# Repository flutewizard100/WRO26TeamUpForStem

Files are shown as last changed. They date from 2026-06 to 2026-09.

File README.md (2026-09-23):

# Future Engineers WRO2026: BRB Robotics

## Team Intro

We are team BRB Robotics from Charlottesville, Virginia, USA.

Dorina, ....

Sagnick, ... a few words about yourself

### Team Pictures
TODO we need to take them today

### Robot Pictures
Here is our robot.
<p>
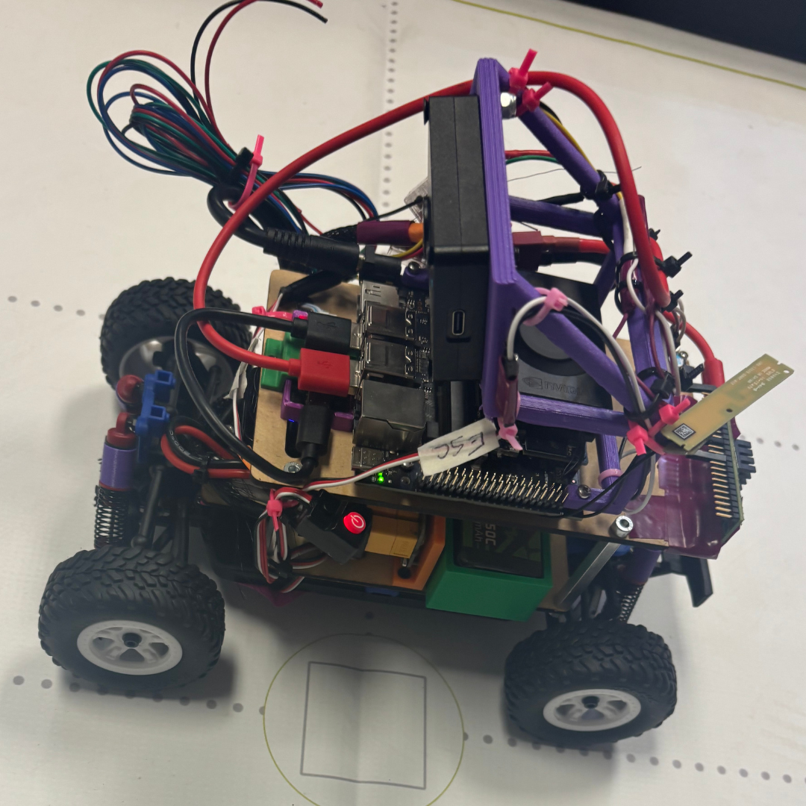
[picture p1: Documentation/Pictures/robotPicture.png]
  
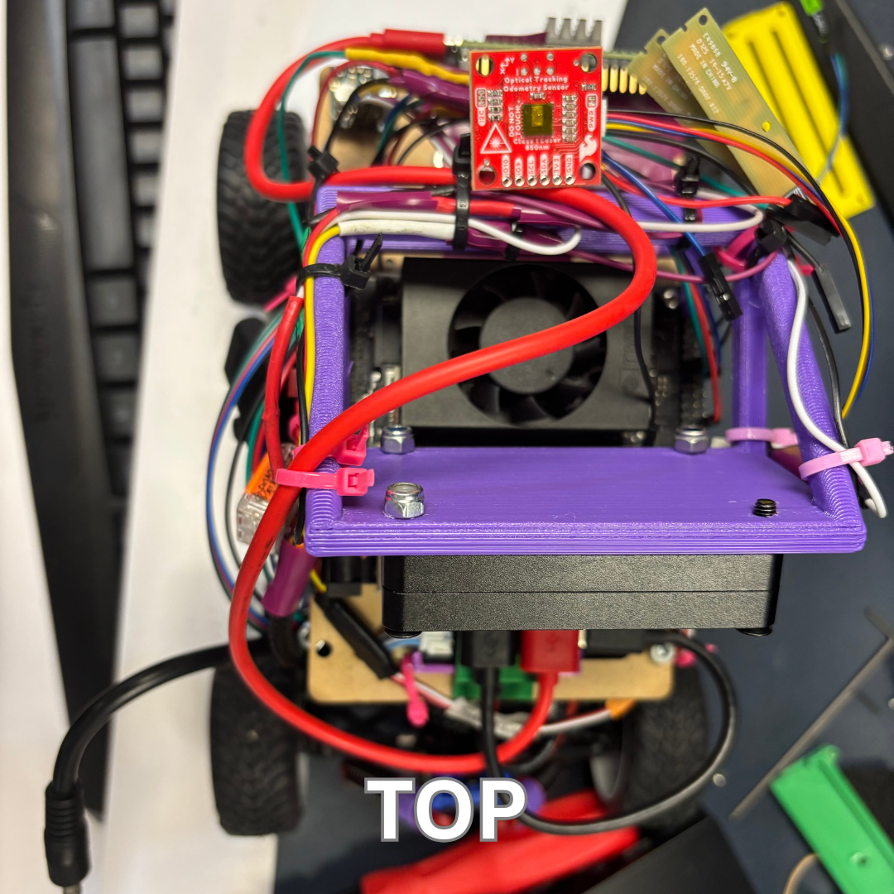
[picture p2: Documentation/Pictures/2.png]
  
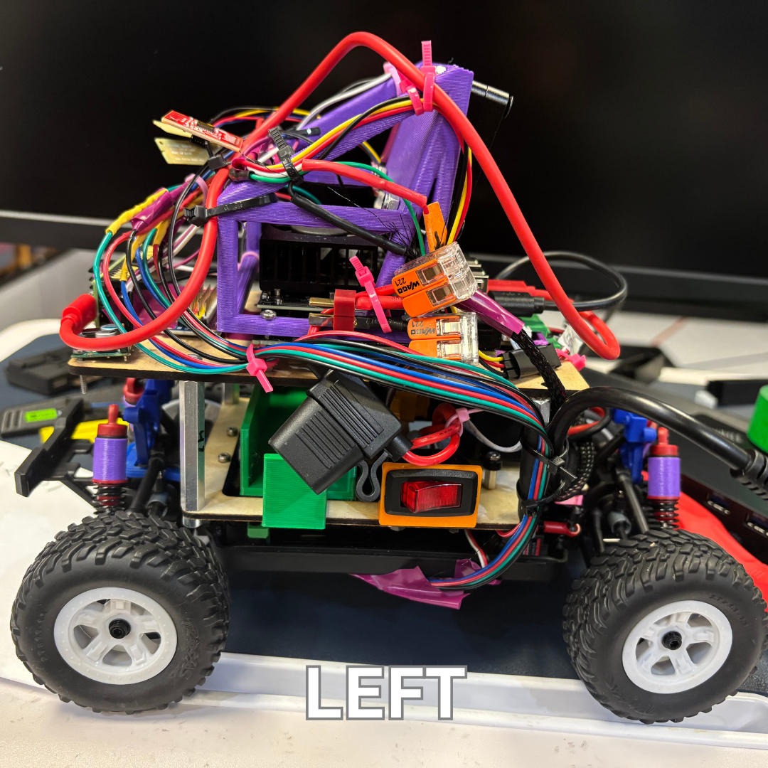
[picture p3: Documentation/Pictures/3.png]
  
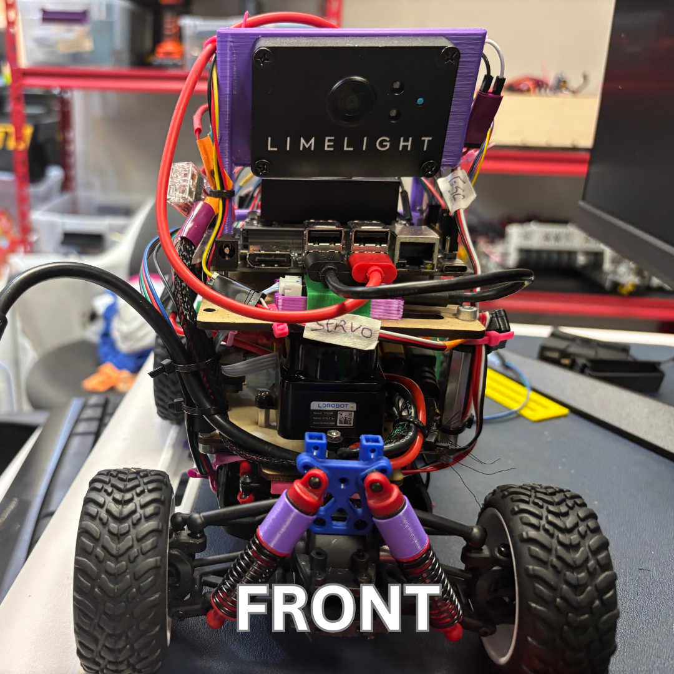
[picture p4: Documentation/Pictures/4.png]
  
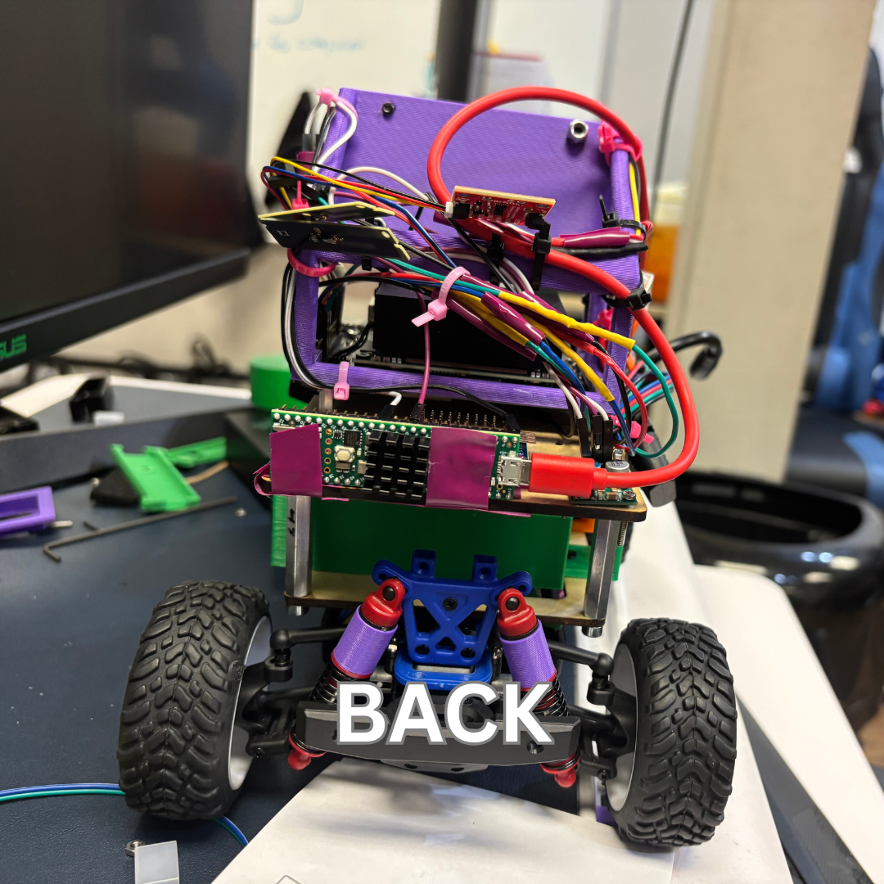
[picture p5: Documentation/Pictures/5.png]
  
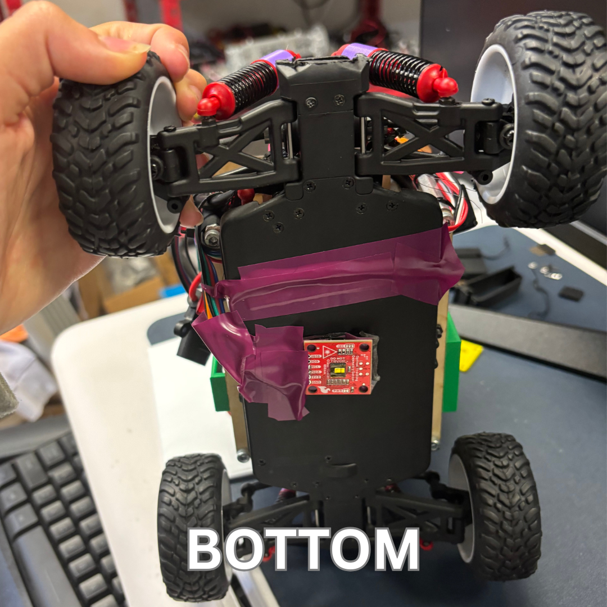
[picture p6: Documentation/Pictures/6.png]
  
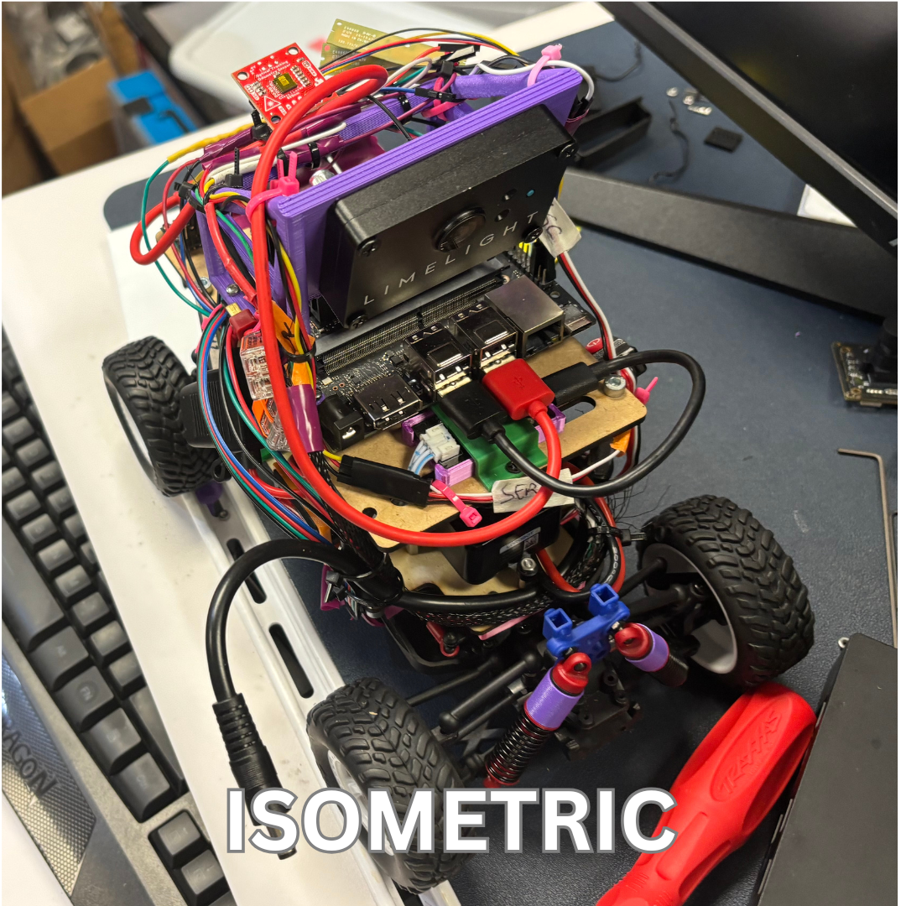
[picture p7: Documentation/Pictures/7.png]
  
</p>

## Bill of Materials

### Mobility/Drive Train

The current version of the robot uses the following components:
- Modified *LaTrax Dessert Prerunner* base available from [Amazon](https://www.amazon.com/dp/B07TV8HMC5?lv=shuf&channelId=500&plpRedirect=mhFallback), [Traxxas](https://traxxas.com/latrax-desert-prerunner-76064-5), or RC cars retailers.
- Motor: *ARRMA MEGA 380 BRUSHED MOTOR* available at [Amazon](https://www.amazon.com/dp/B0CLDRTG4G?ref=fed_asin_title)
- Servo: *Traxxas Metal Gear 2265* available from [Traxxas](https://traxxas.com/2265-high-torque-metal-gear-sub-micro-servo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)  and other retailers.
- Motor gear: *0.5M 60T Steel Spur Gear for Traxxas LaTrax 1/18 RC Cars 7640* available from [Amazon](https://www.amazon.com/dp/B0DK6524Z9?ref=fed_asin_title)  and other retailers.
- Electronic Speed Controller: *HOBBYWING QUICRUN WP 1080 G2 Brushed 2-3s* available from [Amazon](https://www.amazon.com/dp/B0DK6524Z9?ref=fed_asin_title)  and other retailers.

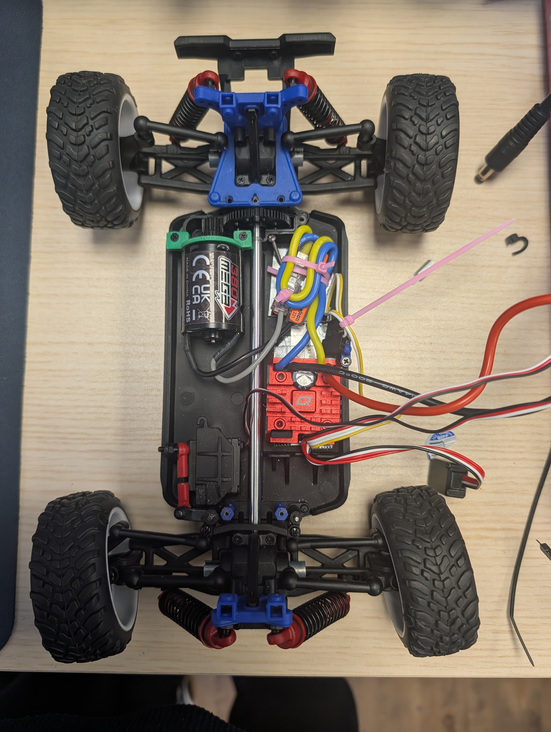
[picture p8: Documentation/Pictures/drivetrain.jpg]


### Power

1. **Battery**: *Ovonic air lipo 3s 3000 mAh 11.1v* available from [Amazon](https://www.amazon.com/dp/B0DF2BL8H1?ref=fed_asin_title) and other retailers.
2. **Power Distribution Board**: *XT60 to 4 Channel XT60 Plug Power Distribution Board* available from [Amazon](https://www.amazon.com/dp/B0FQTJSRVB?ref=fed_asin_title) and other retailers.
3. **Voltage Regulator**: *5V, 3A Step-Up/Step-Down Voltage Regulator S13V30F5* available from [Pololu](https://www.pololu.com/product/4082) and other retailers.
4. Power Switch

### Sensors

1. **IMU + Odometry**: *SparkFun Optical Tracking Odometry Sensor - PAA5160E1 (Qwiic)* available from [Spark Fun](https://www.sparkfun.com/sparkfun-optical-tracking-odometry-sensor-paa5160e1-qwiic.html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)
2. **Lidar**: *STL-27L 360° DTOF LIDAR Sensor (UART, 25m)* available from [DFROBOT](https://www.dfrobot.com/product-2726.html).
3. **Camera**: *Limelight 3A* available from [GoBilda](https://www.gobilda.com/limelight-3a-smart-camera/) and other retailers.

### Computing Components

1. **Main Computer**: *Jetson Orion Nano Developer Kit B01 8G* . The model we used was replaced by [VIDIA Jetson Orin Nano™ Super](https://www.nvidia.com/en-us/autonomous-machines/embedded-systems/jetson-orin/nano-super-developer-kit/).

2. **Low-level Controller**: *Teensy 4.1* available from [Amazon](https://www.amazon.com/dp/B08CTM3279?ref=fed_asin_title) and other retailers.

## Other Materials
- *Pololu Isolated USB-to-I²C Adapter with Isolated Power* available from [Pololu](https://www.pololu.com/product/5397) and other retailers.
- Medium Density Fiberboard/Black Acrylic/Wood for fabricating the two plates.
- PLA Fillament for 3D printing the motor connector, and mounts for various electronic components.
- Screws. We used screws we had in the robotics center including origininal screws from the Traxxas car, [M4 12 mm socket screws](https://www.gobilda.com/m4-socket-head-screws?srsltid=AfmBOooi6TK-TZ9bD9ic7EdKZm5Tyzp37X25FX4myRjO1b7F6xaQRzz2), and a variety of [M3, M2.5, and M2](https://www.mcmaster.com/products/screws/system-of-measurement~metric/thread-size~m3/thread-size~m2-5/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) screws.
- Standoffs. As with the screws, we used standoffs we had available in our lab. We used 4 [GoBilda 8mm REX™ M4 x 0.7mm Threads, 48mm Length](https://www.gobilda.com/1516-series-8mm-rex-standoff-m4-x-0-7mm-threads-48mm-length-4-pack/)  and 4 [Male-Female Threaded Hex Standoffs](https://www.mcmaster.com/products/threaded-spacers/standoffs-2~/male-female-threaded-hex-standoffs-2~~/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).
- [Dupont wires](https://www.amazon.com/dp/B01EV70C78?ref=fed_asin_title)
- Electrical Tape
- small zip ties
- [XT60 female connector to a DC barrel jack plug](https://www.amazon.com/5-5mm%C3%972-1mm-Extension-Connector-Battery-Portable/dp/B0FK2HSQSM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)
- [14×14×7mm Aluminum Heatsink with Conductive Adhesive Tape](https://www.amazon.com/dp/B0CFKHNTDV?ref=fed_asin_title&th=1)
- fuse

## Assembly and Manufacturing

We structured our car in three layers.

### Base Layer

#### Prepare the Base
Strip all the components off the the *LaTrax Dessert Prerunner* until you are left with only the components shown in the picture below. Also, remove the motor gear assembly. Save all the screws for later use.
<p>
  
</p>

#### Install the ESC

The location of the ESC is shown in the image below.
 <p>
  
</p>
We secured the ESC to the base layer with double-sided tape.

#### Attaching the motor

For attaching a stronger motor to the base, we removed the top gearbox housing and 3d printed a new one to fit the new, larger and more powerful motor.

1. Replace the platic gears in the original car with the metal ones.
2. 3D print the motor mount
3. Secure the motor in the new mount making sure the gears connect properly.

#### Attaching the servo

 For replacing the servo we simply got one with the same dimensions and replaced it with no need for any new mounts.
 
#### Attaching the SparkFun Odometry

We also conected the OTOS sensor to the bottom of the car for odometry readings. We used double-sided tape and electrical tape.
 
#### Connection with the first layer

 To be able to mount new compontents we replaced the blue plate with a new wooden laser cut mount. We connected the back directly to the traxxas base using the original screws.
 In the front, we used a 3D printed block to ensure the first layer is perfectly horizontal. We used the original screws to connect the front of the first layer.

### First Layer

This layer consists of a laser-cut, wooden base plate that holds mounts for electronic components. Mounts for the battery, the on/off switch,and the Power Distribution Board are 3D printed using PLA and screwed into the base plate. The Lidar is simply mounted by screwing it in directly to the wooden plate. It also supports four metal GoBilda standoffs that connect the top plate. We choose wood for the material because it is easy and fast to laser cut, and it is less expensive so we have lots of spare material in case the top and middle plates break.

<p>
  
  
</p>

### Second Layer

The top plate is much like the middle plate; except for the shape and the electronics it holds. It is also made of wood and is laser-cut and attaches four different components:
- The Jetson Nano is directly screwed into the board suported by standoffs.
- We connected the teensy perpendicular to the wooden plate.
- The 3D printed camera mount is screwed into other holes on the Nano board.
- The I2C to USBC adapter is connected using mounts.
 <p>
  
  
 </p>

## Power Wiring Diagram

As seen from the diagram below we have three separate braches powered directly from the battery so that a power hungry component does not starve others.

1. Power Distribution board (PBD) ==> ESC ==> Motor
2. PBD ==> Step-Down Voltage Regulator ==> servo (power+ground) and Teensy (ground)
We planned to power the teensy from the Voltage Regulator. For software development it is easier if we power the jetson from the wall and power the Teensy, lidar, and camera from the jetson.
A robust competition wiring is to connect the Teensy to the Jetson using a data only cable and power from the Voltage Regulator.
3. PBD ==> Jetson

==> Camera through the USBC to USBA cable

==> I2C adapter with a USBC to USBA cable ==> Lidar with an I2C cable

==> Teensy with MicroUSB to USBC or USBA

==> Odometry (3.3V pin + ground)

## Data Wiring

The connecting cables between Jetson Orin and lidar, camera, and Teensy are also data cables.

The servo control wire is connected to the Teensy, as well as the ESC control wire.

The odometry control wires (SDL and SCL) are connected directly to the first I2C bus on the Jetson.



## Operating System and Libraries

1. Follow [these instructions](https://ubuntu.com/download/nvidia-jetson#jetson-orin-nano) to install Ubuntu 24.04 on the Jetson Orin.
2. Follow [these instructions](https://docs.ros.org/en/jazzy/Installation.html) to install the ROS2 Jazzy library.
3. Follow [these instructions](https://github.com/micro-ros/micro_ros_setup) to install the [micro-ROS] on the Teensy.

## The stucture of the software

The ROS2 system relies on a process called `ros_core` which facilitates the communication between different parts the the robot.
Each sensor and actuator has its own process, called a node. The nodes representing physical component nodes are connected to other nodes to implement the entire robot behavior.

The nodes communicate through a publisher-subscriber mechanism. Nodes can subscribe to receive messages of a certain type on a topic, whithout know which nodes publishes on that topic. Nodes can also publish on several topics.

To start the entire system of nodes, ROS uses a system of launch files.

Before starting any work session on a terminal, the user must run the following command:
```
source /opt/ros2/jazzy/setup.bash
```

The user must change directory to the `WRO26TeamUpForStem` repository.

To command to compile the code is
```
colcon build
```

Once the build is complete, then the user must run the following command:
```
source install/setup.bash
```

We created a system of launch files to start different parts of the system.

To launch the hardware components we use the command
```
ros launch WRORobot harwdare.launch
```
A graph of the nodes and topics is available [here](hardwarenodegraph.png)

To launch the full simulation stack (sim + Nav2 + SLAM + mission), use:
```
source /opt/ros/jazzy/setup.bash && source install/setup.bash
ros2 launch wro_behavior wro_mission_sim.launch.py
```

On real hardware:
```
ros2 launch wro_behavior wro_mission_hw.launch.py
```

Open and Obstacle challenges share a single unified mission node
(`wro_mission`) that auto-detects which challenge it's running based
on whether any red/green pillars are seen during the run.

When the control code is run in a simulated environment the hardware's behavior is simulated, but the navigation and behavior nodes are the ones used on the real environment.

To launch the full software stack use:
```
source /opt/ros/jazzy/setup.bash && source install/setup.bash
ros2 launch WRORobot
```

# Contents

- our repository is a ROS2 workspace with directories for major software components
1. `ldlidar_ros2` is the software provided by the vendor for the specific lidar we use.
2. `lsm9ds1_handler` and `lsmds1_imu_driver` is software for a 9-axis IMU we planned to use as a backup for the 6-axis IMU that comes with the SparkFun sensor.
3. `slam_toolbox` is a software package that subscribes to the `/odom` and `/scan` and runs a SLAM algorithm and publishes on the topic `map`
4. `WRORobot` contains the nodes representing the harware components.
5. `wro_sim` contains the nodes to creat the simulation and environment
5. `wro_nav2` 
6. `wro_behavior` programs used to code the simulation
- `t-photos` contains two photos of the team: an official team photo and a funny photo with all team members.
- `v-photos` contains six photos of the vehicle from every side, as well as from the top and bottom.
- `video` contains the `video.md` file with a link to a video that includes a driving demonstration.
- `schemes` contains one or more schematic diagrams in JPEG, PNG, or PDF format of the electromechanical components. These diagrams illustrate all of the electronic components and motors used in the vehicle and how they are connected to each other.
- `models` contains the files for models used by 3D printers, laser-cutting machines, and CNC machines to produce the vehicle's components. If there is nothing to add to this folder, the directory can be removed.
- `other` contains additional files that can be used to understand how to prepare the vehicle for the competition. This may include documentation on how to connect to an SBC/SBM and upload files, datasets, hardware specifications, communication protocol descriptions, and other relevant information.

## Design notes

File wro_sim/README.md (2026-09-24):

# wro_sim

Gazebo Harmonic simulation of the WRO Ackermann robot. Bridges the sim to
the same ROS 2 topic/frame contract that the real robot uses, so anything
built against `wro_nav2` and `wro_behavior` runs unchanged on both.

**Do NOT confuse this with Gazebo Classic or Ignition Fortress.** This
package uses `gz-sim-*` plugins and the Jazzy `ros_gz_*` bridges.

## Contents

```
wro_sim/
  worlds/
    wro_field.sdf            # copy of ../wro_map_nav2_sim.sdf
    wro_field.sdf.xacro
  models/wro_bot/
    model.config             # (URDF lives in WRORobot/urdf/, shared with real robot)
  config/
    ros_gz_bridge.yaml       # gz <-> ROS 2 topic map
  hook/
    wro_sim.dsv.in           # prepends GZ_SIM_RESOURCE_PATH
  launch/
    sim.launch.py            # Gazebo + rsp + spawn + bridges (+ optional rviz)
    sim_stack.launch.py      # top-level: sim + Nav2 + behavior
    spawn_robot.launch.py    # standalone spawn
    bridge.launch.py         # standalone bridge
    rviz.launch.py           # standalone rviz
  rviz/sim.rviz
```

## Build

```bash
# From the flat workspace root (this repo).
# rosdep can't resolve workspace-local packages; pass --skip-keys so it
# doesn't error on wro_behavior/wro_nav2/WRORobot. Colcon still respects
# these deps for build ordering.
rosdep install --from-paths . --ignore-src -r -y \
  --skip-keys "WRORobot wro_nav2 wro_behavior"

colcon build --packages-select WRORobot wro_nav2 wro_behavior wro_sim
source install/setup.bash
```

## Run

Sim stack (Gazebo + Nav2 + behavior):

```bash
ros2 launch wro_sim sim_stack.launch.py rviz:=true
# Drop a 2D Nav Goal in RViz, or:
ros2 launch wro_sim sim_stack.launch.py rviz:=true run_goto:=true goal_x:=1.0
```

Just the sim (drive with teleop):

```bash
ros2 launch wro_sim sim.launch.py rviz:=true
ros2 run teleop_twist_keyboard teleop_twist_keyboard
```

Sim + SLAM (build a map online):

```bash
ros2 launch wro_sim sim_stack.launch.py slam:=true rviz:=true

# slam_toolbox is a LIFECYCLE node and slam.launch.py does NOT wire in a
# lifecycle_manager yet. Activate it by hand from another terminal:
ros2 lifecycle set /slam_toolbox configure
ros2 lifecycle set /slam_toolbox activate

# Drive with teleop until the RViz Map display looks acceptable.
ros2 run teleop_twist_keyboard teleop_twist_keyboard

# Save. The transient_local param is REQUIRED — slam_toolbox publishes
# /map with TRANSIENT_LOCAL durability and map_saver_cli defaults to
# VOLATILE, which silently misses every message and prints
# "Failed to spin map subscription" after 2 s.
ros2 run nav2_map_server map_saver_cli -f wro_field \
    --ros-args -p map_subscribe_transient_local:=true
mv wro_field.pgm wro_field.yaml $(ros2 pkg prefix wro_nav2)/share/wro_nav2/maps/
```

The saved map's origin is anchored at the robot's pose when slam_toolbox
was activated, NOT Gazebo's world origin. When you later reload the map
with Nav2 (`slam:=false`), use RViz's 2D Pose Estimate to set the
initial pose to `(0, 0)` yaw `0` in the map frame — that places the
robot at Gazebo world `(0, 1.20)` yaw `3.14159`.

## Topic bridge

Every ROS topic below matches the real hardware's topic name — see
`INTERFACE.md` at repo root for the full contract.

| ROS topic | direction | Gazebo topic | type |
|---|---|---|---|
| `/clock` | gz -> ros | `/clock` | rosgraph_msgs/Clock |
| `/scan` | gz -> ros | `/lidar` | sensor_msgs/LaserScan |
| `/imu/data_raw` | gz -> ros | `/imu` | sensor_msgs/Imu |
| `/odom` | gz -> ros | `/model/wro_bot/odometry` | nav_msgs/Odometry |
| `/tf` | gz -> ros | `/model/wro_bot/tf` | tf2_msgs/TFMessage |
| `/joint_states` | gz -> ros | `/model/wro_bot/joint_state` | sensor_msgs/JointState |
| `/camera_info` | gz -> ros | `/camera_info` | sensor_msgs/CameraInfo |
| `/camera` | gz -> ros | `/camera` | sensor_msgs/Image (via image_bridge) |
| `/cmd_vel` | ros -> gz | `/model/wro_bot/cmd_vel` | geometry_msgs/Twist |

## TODO(measure): placeholders

The URDF (`WRORobot/urdf/wro_bot.urdf.xacro`) is the single source of truth
for physical dimensions on both sim and real robot. Every property in
that file is a placeholder; replace against the physical car or CAD:

- `wheelbase = 0.16`
- `track_width = 0.14`
- `wheel_radius = 0.033`
- `wheel_thickness = 0.025`
- `max_steer_angle = 0.5236` (30 deg)
- Chassis and sensor-mount offsets
- Link masses / inertias

When you update any of these, also update `wro_nav2/params/nav2_params*.yaml`:
- `minimum_turning_radius` on both `SmacPlannerHybrid` and MPPI's
  `AckermannConstraints.min_turning_r`
- Footprint polygon in both costmaps

Sim spawn pose defaults live in `launch/sim.launch.py` (`x=0`, `y=1.20`,
`z=0.103`, `yaw=3.14159` — centered in the narrow (0.60 m) north
corridor, facing west). Adjust to your WRO field start box.

**Do not lower the default `z`.** `z = wheel_radius + chassis_height/2`
(0.033 + 0.070 = 0.103) is the resting height with wheels on the ground.
Spawning below that (e.g. the old `z=0.073`) buries the wheels ~3 cm
underground; physics still runs and joint commands still spin the wheels,
but the chassis stays jammed and never translates. Symptom: `/odom`
integrates a fake forward velocity while `gz model -m wro_bot -p` shows
the pose unchanged.

## Real-hardware decisions already made

- **`odom -> base_link` on hardware is published by `otos_node` only.**
  EKF and Madgwick were removed from `WRORobot/launch/hardware.launch.py`
  on 2026-08-30. See that file's header comment for how to re-enable.
- **Sim `/camera`** is a plain 640x480 image, NOT a Limelight replacement.
  Real hardware uses a Limelight over NetworkTables; sim camera is for
  future ROS-side vision development.

## Gotchas encountered during first bring-up

Kept here so the next engineer doesn't re-diagnose the same problems:

- **Launch it from a plain terminal, not the VSCode Snap terminal.**
  VSCode-as-Snap leaks Snap env into subprocesses, and `gz sim` picks up
  `/snap/core20/current/lib/x86_64-linux-gnu/libpthread.so.0` — an
  ABI-incompatible libpthread — and dies with
  `undefined symbol: __libc_pthread_init, version GLIBC_PRIVATE`. The
  GUI crashes first, then the server gets SIGKILL'd. Use GNOME Terminal
  / kitty / anything non-Snap.
- **Ackermann plugin driven joints must be the rear wheels.**
  `<left_joint>` / `<right_joint>` in
  `gz-sim-ackermann-steering-system` are the joints velocity is
  applied to. Setting them to the front wheels (which are also the
  steering knuckles) results in front wheels spinning kinematically
  with no traction and the car sits still. Fixed in
  `WRORobot/urdf/wro_bot.urdf.xacro`.
- **slam_toolbox does not auto-activate.** See the SLAM run block
  above. Long-term fix: add a `nav2_lifecycle_manager` in
  `wro_nav2/launch/slam.launch.py` with `autostart: true` and
  `node_names: ['slam_toolbox']`.
- **`map_saver_cli` needs `-p map_subscribe_transient_local:=true`.**
  Without it, saves fail with "Failed to spin map subscription".

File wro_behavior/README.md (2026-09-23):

# wro_behavior

High-level behavior for the WRO robot. Mission logic, state machines, and
perception helpers live here.

## Contract

This package consumes the interface pinned in `../INTERFACE.md`. It never
imports from `WRORobot`, `wro_sim`, or any hardware/driver package. If you
find yourself wanting to depend on one, the abstraction is wrong and the
answer is a new topic/action/service in the interface, not a direct import.

## Nodes

- `wro_mission` — unified Open + Obstacle Challenge mission node. State
  machine, direction detection, waypoint dispatch, first-corner guard,
  end-of-race handling.
- `camera_map_augmenter` — subscribes to `/limelight/detections`, projects
  confirmed pillar landmarks into the map frame, publishes them as
  `PointCloud2` on `/camera_obstacles` for Nav2's obstacle layer.
- `sim_limelight_bridge` — sim-only substitute for the real Limelight
  bridge. HSV-detects pillars and lines from `/camera` and publishes
  `vision_msgs/Detection2DArray` on `/limelight/detections`.

## Perception helpers (imported by the nodes above)

- `lidar_perception.LidarPerception` — `/scan` subscription, arc queries,
  forward-edge waypoint generation.
- `camera_perception.CameraPerception` — `/camera_info` + `/limelight/detections`
  subscriptions, pillar/line semantics, pixel → map projection, landmark
  accumulator.

## Run

Sim, full stack (Gazebo + Nav2 + SLAM + mission):
```bash
ros2 launch wro_behavior wro_mission_sim.launch.py
```

Real hardware:
```bash
ros2 launch wro_behavior wro_mission_hw.launch.py
```

Trigger the start button from a terminal (equivalent to pressing the
force sensor):
```bash
ros2 topic pub --once /start_button std_msgs/msg/Bool "{data: true}"
```

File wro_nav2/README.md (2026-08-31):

# wro_nav2

Nav2 configuration, behavior tree, maps, RViz, and launch files for the WRO
Ackermann robot. Config-only — no C++ / Python nodes, no vendored Nav2.

## What's in here

```
wro_nav2/
  params/
    nav2_params.yaml       # real-hardware params (use_sim_time: false)
    nav2_params_sim.yaml   # sim-time params (use_sim_time: true, tighter inflation)
  bt/
    wro_navigate_to_pose.xml   # Nav2's default BT with Spin removed
  maps/
    wro_field.yaml         # placeholder blank 4x4 m map
    wro_field.pgm
    README.md              # how to regenerate / SLAM a real one
  rviz/
    nav2.rviz              # map + costmaps + scan + paths + AMCL pose
  launch/
    nav2.launch.py         # full Nav2 stack (wraps nav2_bringup)
    localization.launch.py # AMCL + map_server + lifecycle_manager subset
    slam.launch.py         # slam_toolbox + Nav2 planning (no AMCL/map_server)
```

## Build

```bash
# from your ROS 2 Jazzy workspace (this repo is a flat workspace — no src/)
colcon build --packages-select wro_nav2
source install/setup.bash
```

## Run

Real robot, pre-built map + AMCL:

```bash
ros2 launch wro_nav2 nav2.launch.py
```

With SLAM instead of AMCL (building a map online):

```bash
ros2 launch wro_nav2 slam.launch.py
# slam_toolbox does not auto-activate — transition it by hand:
ros2 lifecycle set /slam_toolbox configure
ros2 lifecycle set /slam_toolbox activate
```

`slam.launch.py` does not yet include a `nav2_lifecycle_manager` for
slam_toolbox. TODO: add one with `autostart: true` and
`node_names: ['slam_toolbox']` so activation is automatic.

Save the resulting map (transient_local flag is required — see
`wro_sim/README.md` for the full explanation):

```bash
ros2 run nav2_map_server map_saver_cli -f wro_field \
    --ros-args -p map_subscribe_transient_local:=true
mv wro_field.pgm wro_field.yaml \
   $(ros2 pkg prefix wro_nav2)/share/wro_nav2/maps/
```

Localization-only (no planner/controller):

```bash
ros2 launch wro_nav2 localization.launch.py
```

RViz:

```bash
rviz2 -d $(ros2 pkg prefix wro_nav2)/share/wro_nav2/rviz/nav2.rviz
```

## Design notes

- **Planner:** `nav2_smac_planner::SmacPlannerHybrid` with `motion_model: DUBIN`
  and `minimum_turning_radius: 0.30` (approx `wheelbase / tan(max_steer)` =
  `0.16 / tan(30 deg)` = 0.277). Bumped to 0.30 for margin.
- **Controller:** `nav2_mppi_controller::MPPIController` with
  `motion_model: Ackermann` and matching `AckermannConstraints.min_turning_r`.
- **Behaviors:** `wait`, `backup` (dist 0.15 m), `assisted_teleop`. `Spin` is
  **not** included — the Ackermann robot cannot spin in place.
- **AMCL:** `DifferentialMotionModel`. Acceptable for a small Ackermann on a
  smooth WRO field per plan section 2.2; revisit if pose drift is visible.
- **Footprint:** rectangle from chassis dims (0.28 x 0.16 m), not a radius.

## TODO(measure): placeholders to replace

These need real values from the physical robot / `WRO Chassis` CAD:

- `wheelbase = 0.16 m` -> `params/nav2_params*.yaml` (used indirectly via
  `minimum_turning_radius`) and `wro_sim/models/wro_bot/wro_bot.urdf.xacro`.
- `max_steer_angle = 0.5236 rad` -> same URDF, same `minimum_turning_radius`
  calculation.
- Chassis footprint corners `[[0.14, 0.08], ...]` -> both param files,
  local and global costmap.
- Max linear velocity `vx_max: 0.5`, min `vx_min: -0.35` in MPPI + velocity
  smoother -> tune to your motor limits.
- Max angular velocity `wz_max: 1.9`, rotational accel `3.2` in
  behavior_server + velocity_smoother.
- Map (`maps/wro_field.pgm` is a 4x4 m blank). See `maps/README.md`.

## Decisions the user still needs to confirm

- **TF owner on hardware.** This task assumes `ekf_node` publishes
  `odom -> base_link` (i.e. `WRORobot/config/ekf.yaml` keeps
  `publish_tf: true`). `WRORobot/WRORobot/otos_node.py` currently also
  publishes that transform — that's a **duplicate tf publisher** and will
  cause TF_REPEATED_DATA on the real robot. Choose one owner. See
  `wro_sim/README.md` "Known bugs from the plan not fixed here".
- **Camera in sim.** The sim exposes a plain 640x480 image on `/camera` (see
  `wro_sim`). Real hardware uses a Limelight over network tables — the sim
  camera is **not** a Limelight equivalent, only a placeholder for future
  ROS-side vision experiments.

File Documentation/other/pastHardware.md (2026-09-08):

# Contents:
### TODO

## Past Limelight Mount
 
 For our first attempt to mount the lidar we removed the front bumper from the LaTrax Desert Prerunner in order to attach the Limelight camera mount, which was 3d printed like many of the mounts in this autonomous vehicle.

333scrnsht

222scrnsht

these pictures show the limelight mount 3d print.

## First Prototype

#### The first prototype has a 3d printed base:

444scrnshtscrnsht555 1

#### but in the base you see here, there are only mounts for the Jetson Nano and the Arduino Teensy, but no mount for the motor or battery. So, to fix those issues, we 3d printed another base and moved the board mounts to the top plate:

666scrnsht

777 7 screenshots for documentation

here is the new prototype for the base:

888 8 screenshot for documentation

#### There are several reasons, though, to why we did not use this base prototype in the competition. First, the servo for the autonomous vehicle was too weak, and under the circumstances we did not have enough time to create an adapter to a stronger servo. Second, already listed, is the fact that we did not have enough time to perfect the existing prototype or create a new one from scratch, but we were creating a different, remote-controlled-car-based autonomous vehicle, that was used instead.

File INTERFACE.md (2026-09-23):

# WRO26 Robot Interface Contract

This document pins the interface between the three layers of the stack:

- **Hardware** (`WRORobot/`, drivers) OR **Sim** (`wro_sim/`) — one of the two
  publishes the sensor topics and consumes `/cmd_vel`.
- **Navigation** (`wro_nav2/`) — plans, controls, localizes.
- **Behavior** (`wro_behavior/`) — mission logic. Never touches hardware or
  sim internals.

Both sides of every arrow below MUST hold in both sim and on real hardware.
Any change to this file requires review from an engineer on each side.

---

## Frames

```
map → odom → base_link → { base_laser, imu_link, camera_link, *_wheel_* }
                                                       ↓
                                              camera_optical_frame
```

- `map` — global fixed frame. Published by AMCL (`wro_nav2/nav2.launch.py`)
  or by `slam_toolbox` (`wro_nav2/slam.launch.py`). Never published by
  anything else.
- `odom` — smooth-drift odom parent. Publisher differs by side:
  - **Sim**: `gz-sim-ackermann-steering-system` plugin, bridged as
    `/model/wro_bot/tf` → `/tf`.
  - **Real robot**: `ekf_filter_node` (robot_localization) fuses three
    sources into a single filtered pose and owns the `odom → base_link`
    TF edge. Sources: `/odom` from `otos_node` (primary, OTOS),
    `/odometry/laser` from `laser_scan_matcher` (LiDAR scan-to-scan),
    `/imu/data` from `imu_filter_madgwick` (yaw + yaw rate, no mag).
    If OTOS goes silent for >300 ms, EKF drops it and integrates from
    remaining sources — see WRORobot/config/ekf.yaml for weights.
    `otos_node` publishes `/odom` but not the TF (its `publish_tf` param
    is False). To run OTOS standalone (no fusion) remove the ekf/
    madgwick/scan_matcher nodes from hardware.launch.py and set
    otos_node's `publish_tf` param to True.
- `base_link` — robot body root. Owned by `robot_state_publisher`
  processing `WRORobot/urdf/wro_bot.urdf.xacro`.
- `base_laser`, `imu_link`, `camera_link`, `camera_optical_frame`, wheel
  frames — all published by `robot_state_publisher` from the same URDF.

Only one publisher per TF edge. Any duplication is a bug.

---

## Topics behavior consumes

| Topic | Type | Publisher | Rate |
|---|---|---|---|
| `/scan` | `sensor_msgs/LaserScan` | Sim: bridge from `/lidar`. Real: `ldlidar_ros2`. | ~10 Hz |
| `/odom` | `nav_msgs/Odometry` | Sim: bridge. Real: `otos_node` (raw OTOS pose). | ≥30 Hz |
| `/odometry/filtered` | `nav_msgs/Odometry` | Real: `ekf_filter_node` (OTOS + IMU + scan-matcher fused). | 30 Hz |
| `/odometry/laser` | `nav_msgs/Odometry` | Real: `laser_scan_matcher`. Fallback pose source; EKF consumes. | ≥10 Hz |
| `/imu/data` | `sensor_msgs/Imu` | Real: `imu_filter_madgwick` (Madgwick-filtered orientation). EKF consumes. | ~100 Hz |
| `/tf`, `/tf_static` | `tf2_msgs/TFMessage` | as above per edge | — |
| `/amcl_pose` | `geometry_msgs/PoseWithCovarianceStamped` | Nav2 AMCL | ~2 Hz |
| `/camera/image_raw`, `/camera_info` | `sensor_msgs/Image`, `sensor_msgs/CameraInfo` | Sim: bridge. Real: not published — the Limelight does not stream raw frames; use `/limelight/detections` instead. | ~30 Hz (sim only) |
| `/limelight/detections` | `vision_msgs/Detection2DArray` | Real: `limelight_bridge` (SSD MobileNet on Limelight 3). Sim: not published. `frame_id` is `camera_optical_frame`; each detection carries a bbox in pixels + a 3D pose in the camera-optical frame estimated from bbox height. `results[0].hypothesis.class_id` is the LL label string (e.g. `red_pillar`, `green_pillar`). Empty array published as heartbeat when nothing detected. | 30 Hz |
| `/joint_states` | `sensor_msgs/JointState` | Sim: bridge. Real: TBD. | ~30 Hz |
| `/imu/data_raw` | `sensor_msgs/Imu` | Sim: bridge. Real: `lsm9ds1_imu_driver`. Not currently fused; available for logging. | ~100 Hz |

---

## Topics behavior publishes

| Topic | Type | Consumer |
|---|---|---|
| `/goal_pose` | `geometry_msgs/PoseStamped` | Nav2 (RViz-style single-goal path; testing only) |

---

## Actions behavior calls

| Action | Type | Server |
|---|---|---|
| `/navigate_to_pose` | `nav2_msgs/NavigateToPose` | `bt_navigator` in Nav2 |
| `/follow_waypoints` | `nav2_msgs/FollowWaypoints` | `waypoint_follower` in Nav2 |

---

## Topics behavior/nav publishes → hardware or sim consumes

| Topic | Type | Consumer | Notes |
|---|---|---|---|
| `/cmd_vel` | `geometry_msgs/Twist` | Sim: bridge → AckermannSteering. Real: `Motor` node (ESC) + `Servo` node (steering servo). | Nav2 publishes via `velocity_smoother`; behavior can also publish for teleop-style tests. |

---

## Ackermann kinematics assumptions

`/cmd_vel.linear.x` is the desired forward velocity in m/s.
`/cmd_vel.angular.z` is the desired yaw rate in rad/s.

The controller and drive plugin/driver must convert `(vx, ωz)` to
`(wheel_speed, steering_angle)` using the wheelbase and steering limits
declared in `WRORobot/urdf/wro_bot.urdf.xacro`. If those values change,
both sides must re-read the URDF at launch.

There is no support for `/cmd_vel.linear.y` — the robot cannot strafe.
Nav2 params set `vy_max: 0.0` and `motion_model: Ackermann`.

---

## Guarantees each side must uphold

**Hardware side (`WRORobot/hardware.launch.py`):**
- `/odom` at ≥ 30 Hz; drift < 5 cm over a 30 s straight-line run.
- `/scan` at ≥ 10 Hz; frame_id `base_laser`.
- `/imu/data_raw` at ≥ 100 Hz; frame_id `imu_link`.
- `/cmd_vel` → motion within 50 ms.
- No writes to `/tf` except `odom → base_link` (from `ekf_filter_node`) and
  robot_state_publisher's `base_link → *`.

**Sim side (`wro_sim/sim.launch.py`):**
- Same rates and frame_ids as above, matched by `ros_gz_bridge`.
- Physics stable at 1× real time on a target dev laptop.

**Nav side (`wro_nav2/nav2.launch.py`):**
- Consumes only the topics/frames listed above.
- Publishes `/cmd_vel` (via smoother) and `map → odom`.

**Behavior side (`wro_behavior/launch/wro_mission_{sim,hw}.launch.py`):**
- Consumes only the topics/actions listed above.
- Never imports from hardware or sim packages.

---

## When something on this list changes

1. Open a PR that edits **only** `INTERFACE.md` first.
2. Get review from one engineer per side.
3. Only after that PR merges, implement the change in the affected packages.

This keeps the two engineers unblocked — if one changes the interface
unilaterally, the other's code will silently break at competition, not at
merge time.

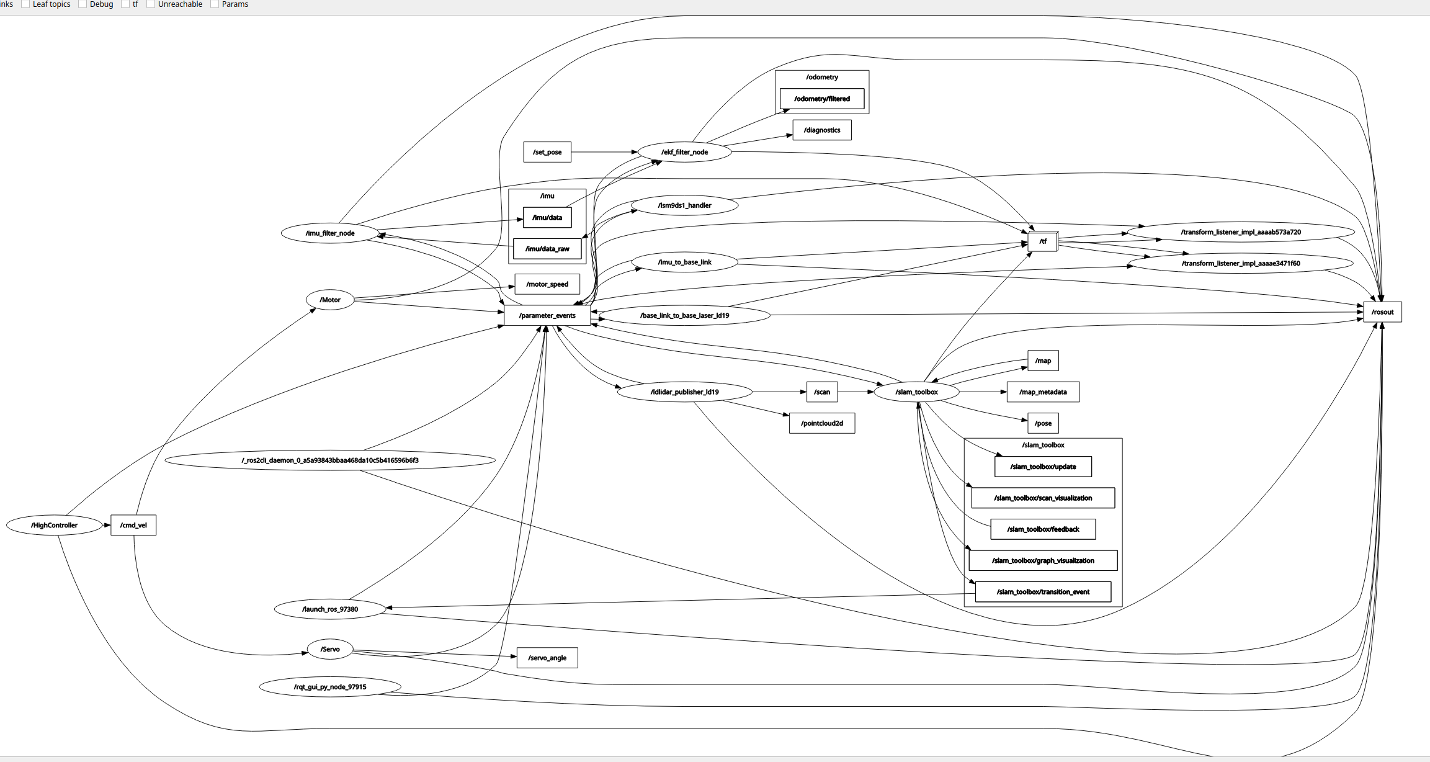
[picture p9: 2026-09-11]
hardwarenodegraph.png

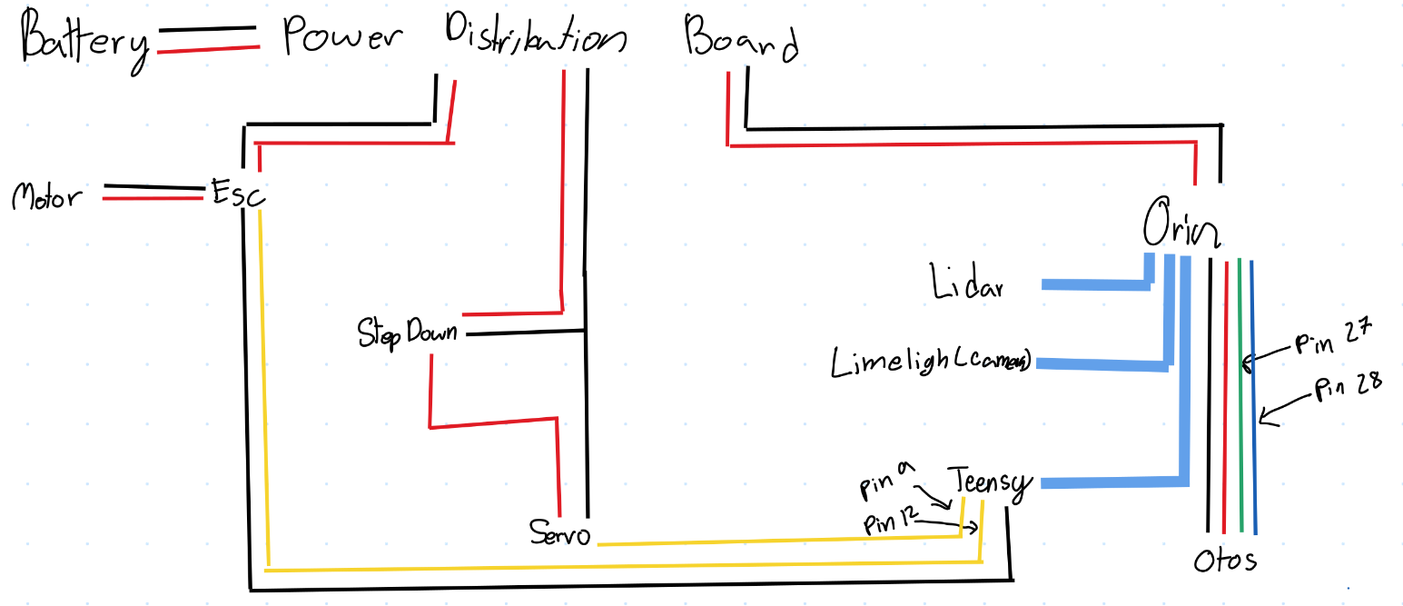
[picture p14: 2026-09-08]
Documentation/schemes/Screenshot From 2026-09-08 13-28-38.png

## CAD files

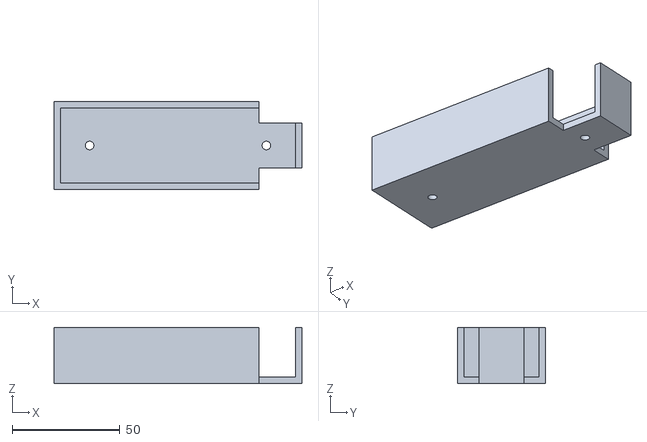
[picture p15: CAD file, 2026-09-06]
Documentation/models/BATTERY HOLDER.stl
115.0 x 41.0 x 26.0

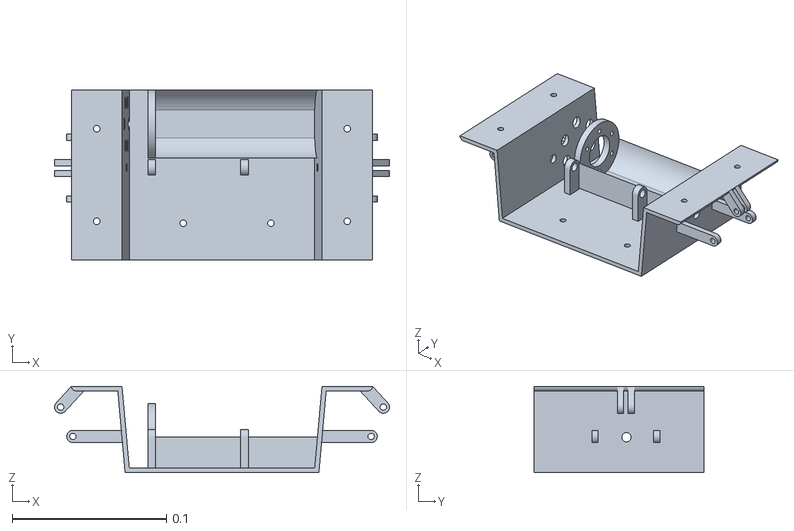
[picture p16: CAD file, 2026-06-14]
WROOldChassis.stl
0.217 x 0.11 x 0.056

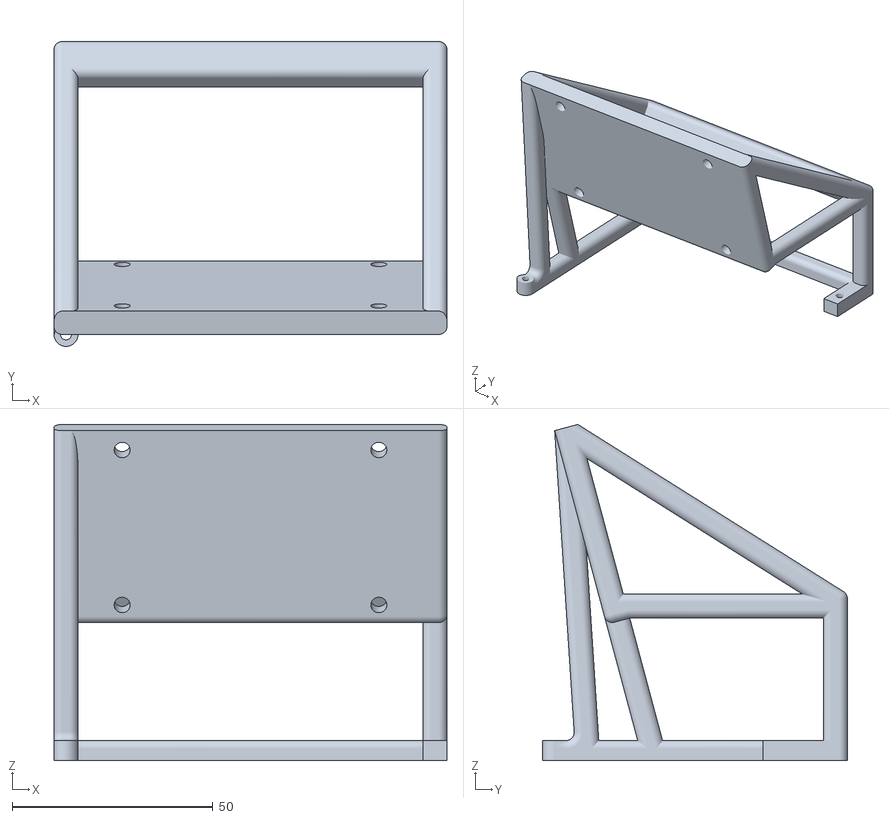
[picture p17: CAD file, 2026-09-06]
Documentation/models/LiDAR holder.stl
98.0 x 76.0 x 83.8

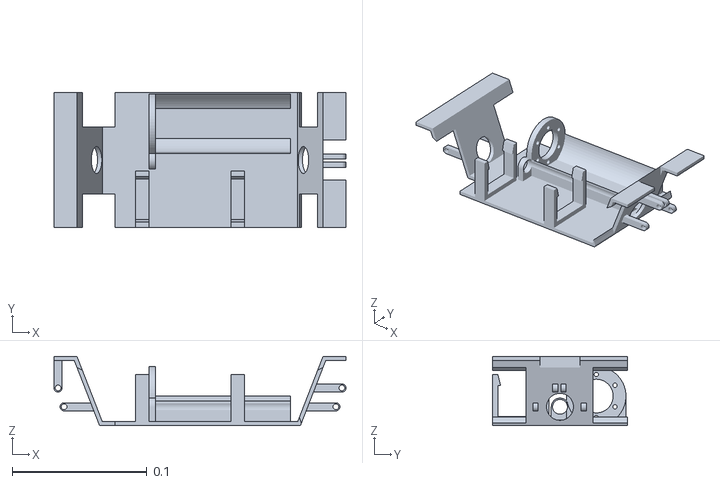
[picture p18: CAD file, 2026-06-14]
WROChassis.stl
0.217 x 0.1 x 0.0515

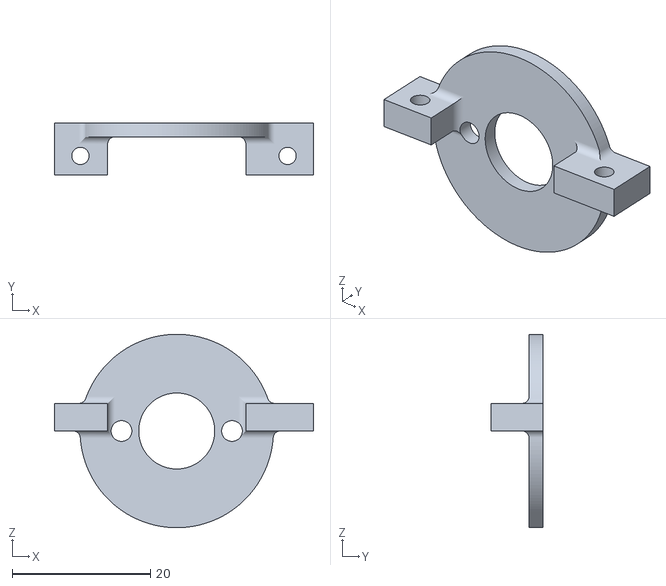
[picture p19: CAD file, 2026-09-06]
Documentation/models/MOTOR MOUNT - Part 1 (2).stl
37.5 x 7.50 x 28.0

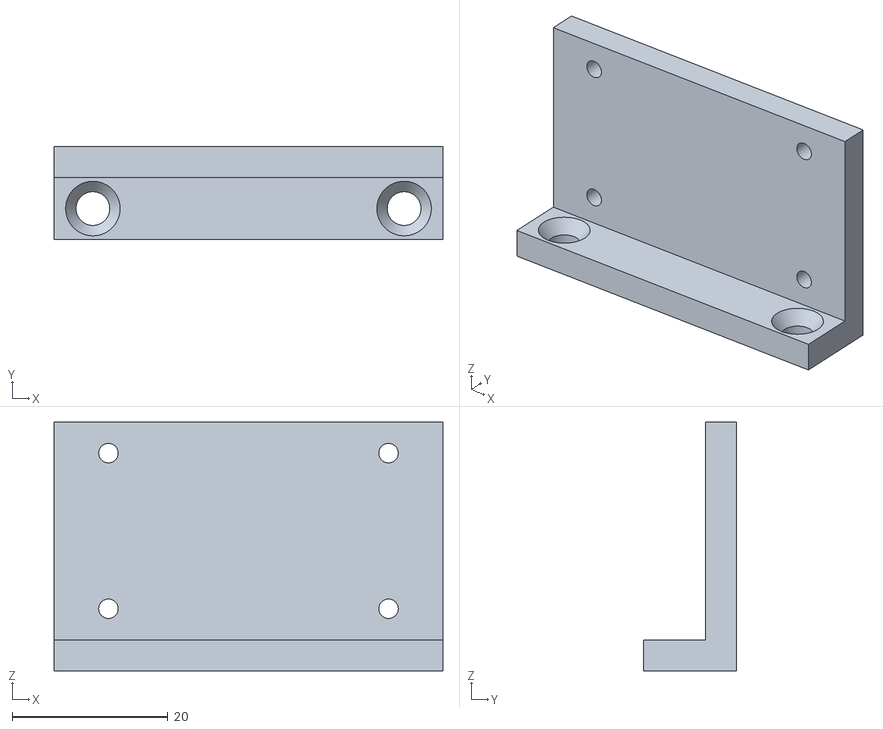
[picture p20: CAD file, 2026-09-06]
Documentation/models/PWR DISTIBUTION MOUNT - Part 1.stl
50.0 x 12.0 x 32.0

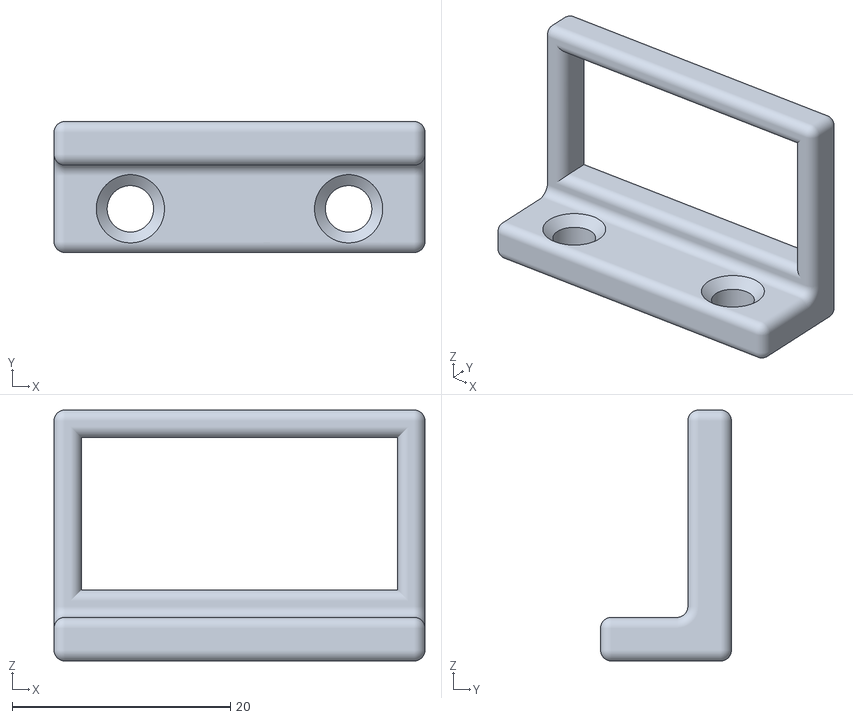
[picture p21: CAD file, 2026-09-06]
Documentation/models/BATRY SWITCH - Part 1.stl
34.0 x 12.0 x 23.0

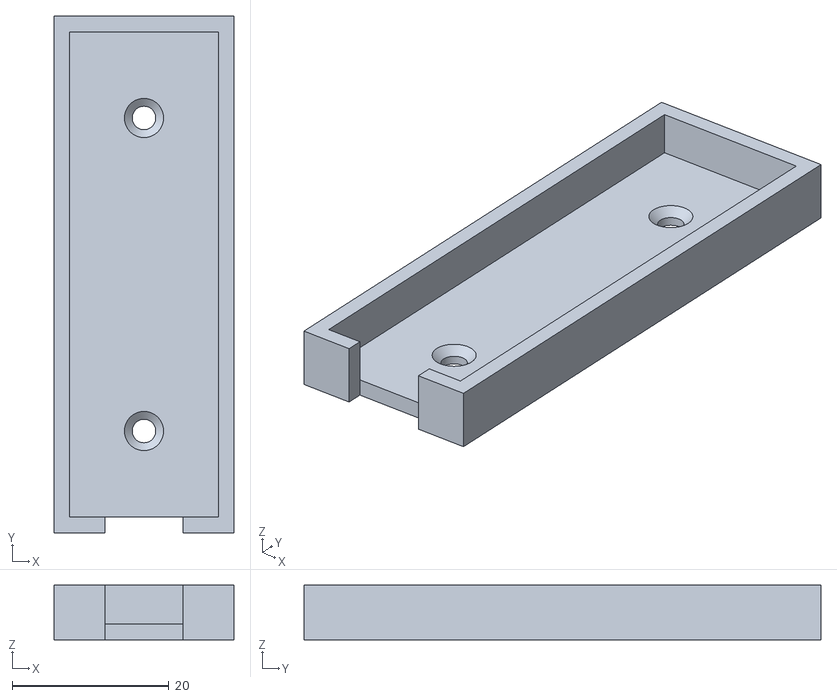
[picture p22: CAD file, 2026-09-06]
Documentation/models/TEENSY MOUNT - Part 1.stl
23.0 x 66.0 x 7.00

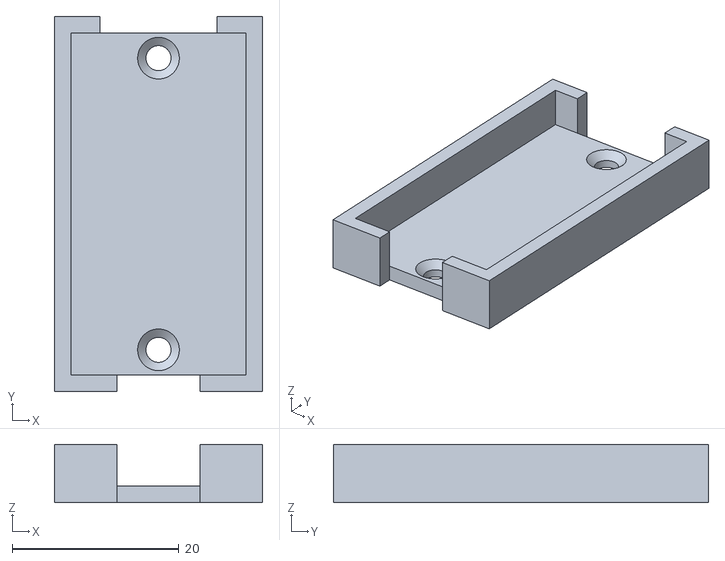
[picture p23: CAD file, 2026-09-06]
Documentation/models/LIDAR BOARD MOUNT - Part 1.stl
25.0 x 45.0 x 7.00

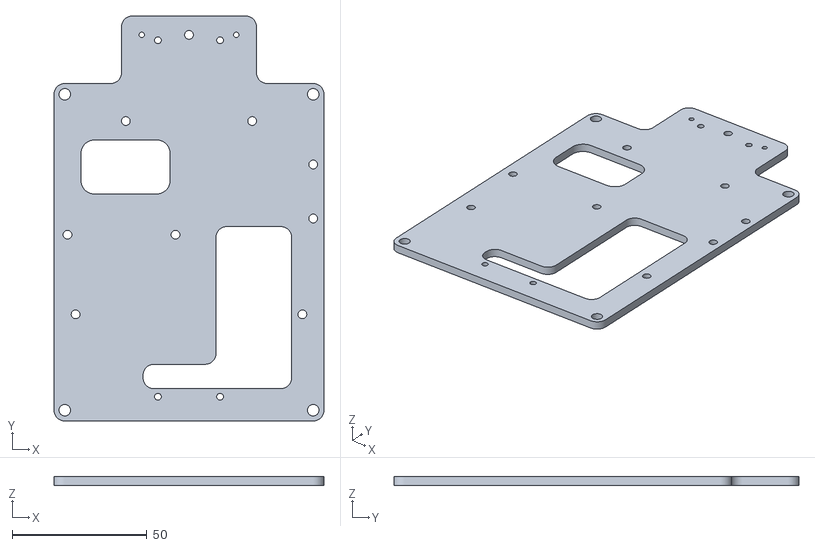
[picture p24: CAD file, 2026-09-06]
Documentation/models/BOTTOM PLATE - Part 1.stl
100.0 x 150.0 x 3.17

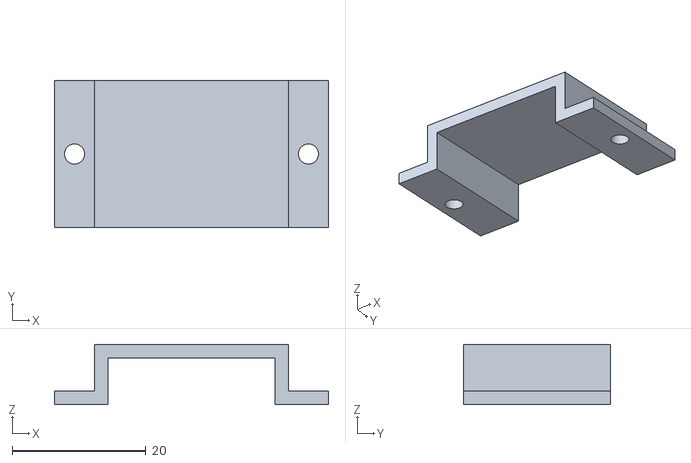
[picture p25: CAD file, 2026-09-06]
Documentation/models/LIDAR BOARD MOUNT - Part 2.stl
41.0 x 22.0 x 9.00

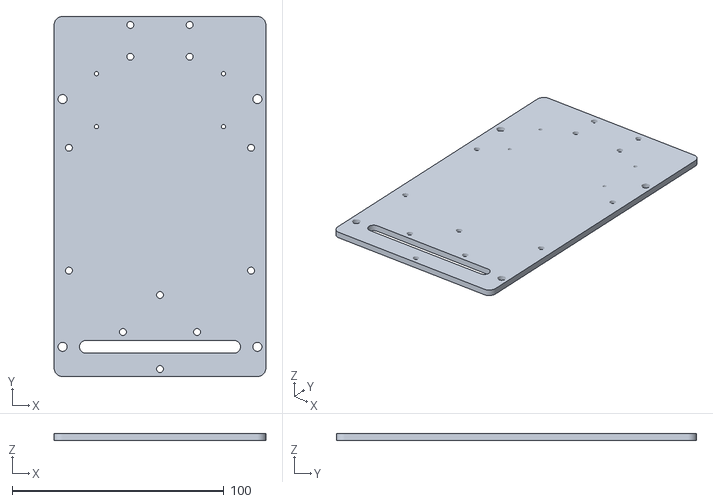
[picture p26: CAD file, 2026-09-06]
Documentation/models/TOP PLATE - Part 1.stl
100.0 x 170.0 x 3.17

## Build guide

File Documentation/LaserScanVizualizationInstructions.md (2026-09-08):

1. Launch the WRORobot package in the ssh terminal

2. Make sure you have the same ROS_DOMAIN_ID as the robot (should be 0) and are connected to the same wifi (may have to set up the ROS_DOMAIN_ID and such in the ~/.bashrc)

3. check by running ros2 node list on a non-ssh terminal. You should still be able to see the same ros2 node list

4. In the non-ssh terminal run rviz2 command

5. Then change the fixed frame to be base_link

6. Add laser scan display to the rviz2

7. If you want to make the dots more bigger or stable, there are some settings underneath the laser scan display (increasing Decay time to 1 should make it more stable) and you can increase the size setting

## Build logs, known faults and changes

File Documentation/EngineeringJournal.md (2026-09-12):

# Contents
- Mobility and Mechanical Design
- Power and Sensor Architecture
- Software Architecture and Obstacle Strategy
- Systems Thinking and Engineering Decisions

## Car Base Iterations

### Version 1.0: 3D-Printed Base

Our first car used a fully 3D-printed body as its main structure. We planned to mount a much larger motor and servo, with all our sensors on top. This did not work because the sensors would not fit, and the body was too bulky and inconvenient.

Version 1.0 chassis designVersion 1.0 additional view

### Version 1.1: Adding a Sensor Platform

We kept the main structure and rearranged parts to make it smaller, stronger, and fit better. We added a flat top layer to mount the sensors, which helped most of them fit. However, the base was still too high for the LiDAR to fit and scan the walls effectively.

Version 1.1 chassis with sensor platform

Version 1.1 additional view

### Version 2.1: Switching to a Premade Base

After testing our 3D-printed base, we switched to the LaTrax Desert Prerunner base. We removed the casing and original structural plate but kept the original servo and motor at first.

We later decided to replace the motor with one recommended by the MIT course and the servo with one recommended by a local RC car expert.

Version 2.1 premade chassis

### Version 2.2: Replacing the Motor and Servo

We replaced the motor with an ARRMA MEGA 380 brushed motor and added a new mount to hold it. We also replaced the servo with a Traxxas 2265 metal-gear servo and added an electronic speed controller (ESC) to control the motor and supply it with power.

Version 2.2 updated components and chassis

## Design Tradeoffs and Changes

We first tried fixing the layout instead of replacing the whole printed base. The flat top layer helped most sensors fit, but it did not solve the LiDAR height problem.

Switching to a premade base still required changes, including removing the casing and structural plate and adding a motor mount. Our main concern was not just fitting the parts, but placing the LiDAR where it could scan the walls effectively.

## Choosing Components

| Component | What We Used | Why We Used It |
|---|---|---|
| Chassis | LaTrax Desert Prerunner base | Our printed bases were too bulky and had problems with sensor space and LiDAR placement. |
| Motor | ARRMA MEGA 380 brushed motor | The MIT course recommended it, it was easy to get, and we already had it. |
| Motor mount | New mount for the replacement motor | To hold the new motor in place. |
| Servo | Traxxas 2265 metal-gear servo | A local RC car expert recommended it, it was easy to find, and we already had it. |
| Electronic speed controller (ESC) | HOBBYWING QUICRUN WP 1080 G2 Brushed 2–3S | To control the motor and supply it with power. |

## Steering and Drivetrain

### Steering
The steering servo moves a set of linkages that change the angle of the front wheels to steer the car.

### Drivetrain
The motor drives all four wheels, with a long driveshaft connecting the front and rear drivetrain. The motor uses a larger gear to drive a smaller gear, increasing speed but reducing torque at that connection.

## Mechanical Stability

### Motor Mount
The motor mount screws into the chassis to hold the motor in place.

### Component Mounts
The battery, on/off switch, and Power Distribution Board use 3D-printed PLA mounts that screw into the wooden plate.

### Plate Supports
Four metal GoBilda standoffs connect the two levels and support the top plate. 

## Power Distribution

Power goes from the battery through a fuse and switch to the PDB, which splits it into three branches:

```text
Battery → Fuse → Switch → PDB
                          ├── ESC → Motor
                          ├── Step-Down Converter → Servo
                          └── Orin
```

The ESC controls the motor, the step-down converter lowers the voltage for the servo, and the last branch powers the Orin.

Our battery is an 11.1V 3S LiPo, which is fine for the motor and the Orin but would immediately fry the servo, since the Traxxas 2265 is rated for around 6V. The Pololu S13V30F5 step-down regulator drops the 11.1V down to a clean 5V, which is safe for the servo and is also the voltage most of our smaller electronics expect. This way one battery powers the whole car, and each device gets the voltage it actually needs.

Only power connections are shown, not signal wires.

## Sensors

| Sensor | Model | What We Use It For | Why We Chose It | Where It Is Mounted | Why This Position |
|---|---|---|---|---|---|
| LiDAR | LDRobot LD19 | Build a 2D map using light reflected off walls and obstacles | We wanted to measure the distance to walls around the car, not just directly in front of it. | Screwed to the Level 1 plate | Keeps the LiDAR below the top of the walls so it can scan them. |
| Camera | GoBilda Limelight 3A | Detect corners and obstacle colors | It gives us information about colors in front of and slightly to the sides of the car, rather than only directly below it. | Elevated above the car and mounted at an angle | Allows the camera to see the far front wall from any position. |
| Odometry | SparkFun Optical Tracking Odometry Sensor | Track the robot’s position on the field | It is small, easy to mount, and fits under the car base. | Under the LaTrax base, in the center of the robot | Places the sensor at the correct height and position for accurate readings. |

## Sensor Consideration 

### LiDAR

Before choosing our current LiDAR, we considered two other models.

#### RPLIDAR A1

We first considered the RPLIDAR A1 because we already owned it and had heard it was reliable.

RPLIDAR A1

We decided against it because it was too large, and its external motor took up extra space.

#### RPLIDAR A3

We then switched to the RPLIDAR A3 because we expected it to be more reliable. Its internal motor also gave it a more compact shape that was easier to mount.

RPLIDAR A3

However, it was still too large to fit on our robot. It was also heavy and expensive, so we switched to our current LiDAR, the LDRobot LD19.

## Odometry Calibration

Our SparkFun OTOS sensor does not report distance and rotation perfectly, so we calibrate it before use. We drove the car along a known straight line and compared the reported distance to the real distance to get a linear scalar of 0.99554497057, then rotated the car through a known angle and did the same to get an angular scalar of 0.99995448187. We also run `calibrate_otos.py`, which records the sensor for 15 seconds while the car is still and measures the standard deviation of its readings, since the OTOS reports small nonzero values even when nothing is moving. Those standard deviations become the covariances we give the EKF, so it knows how much to trust the sensor.

## Scan Filter

Our LiDAR sometimes returns bad readings, so we run every scan through a filter before using it. Any point closer than 10 cm is dropped because it is almost always a reflection off the car itself, and any point farther than 4 m is dropped because the LiDAR returns a max-range value when it does not hit anything. A speckle filter then removes isolated points that differ from their neighbors by more than 0.5 m, which cleans up random spikes. This leaves us with a scan that only contains real walls and obstacles.

## Training the Limelight

We run object detection on the Limelight to find the red and green pillars, the orange and blue corner lines, and the black outer wall. To train it we took pictures of the real field from many angles, distances, and lighting conditions, then drew bounding boxes around each object and labeled it with the correct class. The Limelight web interface trained a neural detector on this data, which we then deployed to the camera. The pillar detections tell us which side to pass an obstacle on, while the corner lines and black wall give us fixed features we can use to localize the car on the field.

## Open Loop Logic

For our open loop, we use a state machine with 5 states, each one leading to another:

(Init) Our initial state allows the robot to get set and ensures all the sensors are ready and the topics have information before we begin to use them in our calculations. Once finished, the state is set to Lane Follow.

(Lane Follow) Our lane follow state keeps the robot speed set on cmd_vel to go forward until the sensors detect a corner, which sets the state to Corner, unless the number of corners is 12, meaning that the robot has finished 3 full laps, which makes the state Park.

(Corner) Our corner state keeps the robot turning until the sensors detect that the robot is in between the 2 walls. Once it is, the state is set to Lane Follow.

(Park) Our parking state keeps the robot going forward until it is halfway in the tunnel, where it started, and then changes the state to Stop.

(Stop) Our stop state keeps the robot from moving and does not activate a new state.



### Obstacle Loop Logic
For our obstacle loop, we use a state machine with 6 states, each one leading to another:

(Init) Our initial state allows the robot to get set and ensures all the sensors are ready and the topics have information before we begin to use them in our calculations. Once finished, the state is set to Lane Follow.

(Lane Follow) Our lane follow state keeps the robot speed set on cmd_vel to go forward until the sensors detect a corner or an obstacle, which sets the state to obstacle or corner depending on detection, unless the number of corners is 12, meaning that the robot has finished 3 full laps, which makes the state Park.

(Corner) Our corner state keeps the robot turning until the sensors detect that the robot is in between the 2 walls. Once it is, the state is set to Lane Follow.

(Obstacle) Our obstacle state keeps the robot turns either left or right of obstacle depending on the color detection of the camera, Once it finishes, the state sets back to Lane Follow.

(Park) Our parking state keeps the robot going forward until it is halfway in the tunnel, where it started, and then changes the state to Stop.

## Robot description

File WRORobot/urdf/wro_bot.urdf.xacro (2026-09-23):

<?xml version="1.0"?>
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
<robot xmlns:xacro="http://www.ros.org/wiki/xacro" name="wro_bot">

  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
  <xacro:property name="wheelbase" value="0.18"/>
  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
  <xacro:property name="track_width" value="0.136"/>
  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
  <xacro:property name="wheel_radius" value="0.033"/>
  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
  <xacro:property name="wheel_thickness" value="0.028"/>
  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
  <xacro:property name="max_steer_angle" value="0.5236"/>

  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
  <xacro:property name="chassis_length" value="0.28"/>
  <xacro:property name="chassis_width" value="0.16"/>
  <xacro:property name="chassis_height" value="0.085"/>

  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
  <xacro:property name="lidar_xyz" value="0.0 0.05 ${0.085-chassis_z}"/>
  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
  <xacro:property name="imu_xyz" value="0.0 0.00 0.01"/>
  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
  <xacro:property name="camera_x" value="0.02162"/>
  <xacro:property name="camera_y" value="0.0"/>
  <xacro:property name="camera_z" value="0.0466"/>
  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
  <xacro:property name="camera_pitch" value="${pi/9}"/>

  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
  <xacro:property name="half_l" value="${wheelbase/2}"/>
  <xacro:property name="half_t" value="${track_width/2}"/>
  <xacro:property name="chassis_z" value="${wheel_radius + chassis_height/2}"/>
  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
  <xacro:macro name="inertial_box" params="mass x y z">
    <inertial>
      <origin xyz="0 0 0" rpy="0 0 0"/>
      <mass value="${mass}"/>
      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
    </inertial>
  </xacro:macro>

  <xacro:macro name="inertial_cyl" params="mass r l">
    <inertial>
      <origin xyz="0 0 0" rpy="0 0 0"/>
      <mass value="${mass}"/>
      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
    </inertial>
  </xacro:macro>

  <xacro:macro name="wheel_link" params="name">
    <link name="${name}">
      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
      <xacro:inertial_cyl mass="0.05" r="${wheel_radius}" l="${wheel_thickness}"/>
    </link>
  </xacro:macro>

  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
  <link name="base_footprint"/>

  <link name="base_link">
    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
    <xacro:inertial_box mass="1.5" x="${chassis_length}" y="${chassis_width}" z="${chassis_height}"/>
  </link>

  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
  <joint name="base_footprint_to_base_link" type="fixed">
    <parent link="base_footprint"/>
    <child link="base_link"/>
    <origin xyz="0 0 ${chassis_z}" rpy="0 0 0"/>
  </joint>

  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
  <link name="front_left_wheel_steer">
    <xacro:inertial_box mass="0.02" x="0.02" y="0.02" z="0.02"/>
  </link>
  <link name="front_right_wheel_steer">
    <xacro:inertial_box mass="0.02" x="0.02" y="0.02" z="0.02"/>
  </link>

  <joint name="front_left_wheel_steer_joint" type="revolute">
    <parent link="base_link"/>
    <child link="front_left_wheel_steer"/>
    <origin xyz="${half_l} ${half_t} ${-chassis_height/2}" rpy="0 0 0"/>
    <axis xyz="0 0 1"/>
    <limit lower="${-max_steer_angle}" upper="${max_steer_angle}" effort="10.0" velocity="5.0"/>
  </joint>

  <joint name="front_right_wheel_steer_joint" type="revolute">
    <parent link="base_link"/>
    <child link="front_right_wheel_steer"/>
    <origin xyz="${half_l} ${-half_t} ${-chassis_height/2}" rpy="0 0 0"/>
    <axis xyz="0 0 1"/>
    <limit lower="${-max_steer_angle}" upper="${max_steer_angle}" effort="10.0" velocity="5.0"/>
  </joint>

  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
  <xacro:wheel_link name="front_left_wheel"/>
  <xacro:wheel_link name="front_right_wheel"/>
  <xacro:wheel_link name="rear_left_wheel"/>
  <xacro:wheel_link name="rear_right_wheel"/>

  <joint name="front_left_wheel_joint" type="continuous">
    <parent link="front_left_wheel_steer"/>
    <child link="front_left_wheel"/>
    <origin xyz="0 0 0" rpy="0 0 0"/>
    <axis xyz="0 1 0"/>
  </joint>

  <joint name="front_right_wheel_joint" type="continuous">
    <parent link="front_right_wheel_steer"/>
    <child link="front_right_wheel"/>
    <origin xyz="0 0 0" rpy="0 0 0"/>
    <axis xyz="0 1 0"/>
  </joint>

  <joint name="rear_left_wheel_joint" type="continuous">
    <parent link="base_link"/>
    <child link="rear_left_wheel"/>
    <origin xyz="${-half_l} ${half_t} ${-chassis_height/2}" rpy="0 0 0"/>
    <axis xyz="0 1 0"/>
  </joint>

  <joint name="rear_right_wheel_joint" type="continuous">
    <parent link="base_link"/>
    <child link="rear_right_wheel"/>
    <origin xyz="${-half_l} ${-half_t} ${-chassis_height/2}" rpy="0 0 0"/>
    <axis xyz="0 1 0"/>
  </joint>

  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
  <link name="base_laser">
    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
    <xacro:inertial_cyl mass="0.05" r="0.025" l="0.03"/>
  </link>

  <joint name="base_link_to_base_laser" type="fixed">
    <parent link="base_link"/>
    <child link="base_laser"/>
    <origin xyz="${lidar_xyz}" rpy="0 0 -1.5708"/>
  </joint>

  <link name="imu_link">
    <xacro:inertial_box mass="0.01" x="0.02" y="0.02" z="0.005"/>
  </link>

  <joint name="base_link_to_imu_link" type="fixed">
    <parent link="base_link"/>
    <child link="imu_link"/>
    <origin xyz="${imu_xyz}" rpy="0 0 0"/>
  </joint>

  <link name="camera_link">
    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
    <xacro:inertial_box mass="0.02" x="0.02" y="0.04" z="0.02"/>
  </link>

  <joint name="base_link_to_camera_link" type="fixed">
    <parent link="base_link"/>
    <child link="camera_link"/>
    <origin xyz="${camera_x} ${camera_y} ${camera_z}" rpy="0 ${camera_pitch} 0"/>
  </joint>

  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
  <link name="camera_optical_frame"/>
  <joint name="camera_link_to_optical" type="fixed">
    <parent link="camera_link"/>
    <child link="camera_optical_frame"/>
    <origin xyz="0 0 0" rpy="${-pi/2} 0 ${-pi/2}"/>
  </joint>

  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

</robot>

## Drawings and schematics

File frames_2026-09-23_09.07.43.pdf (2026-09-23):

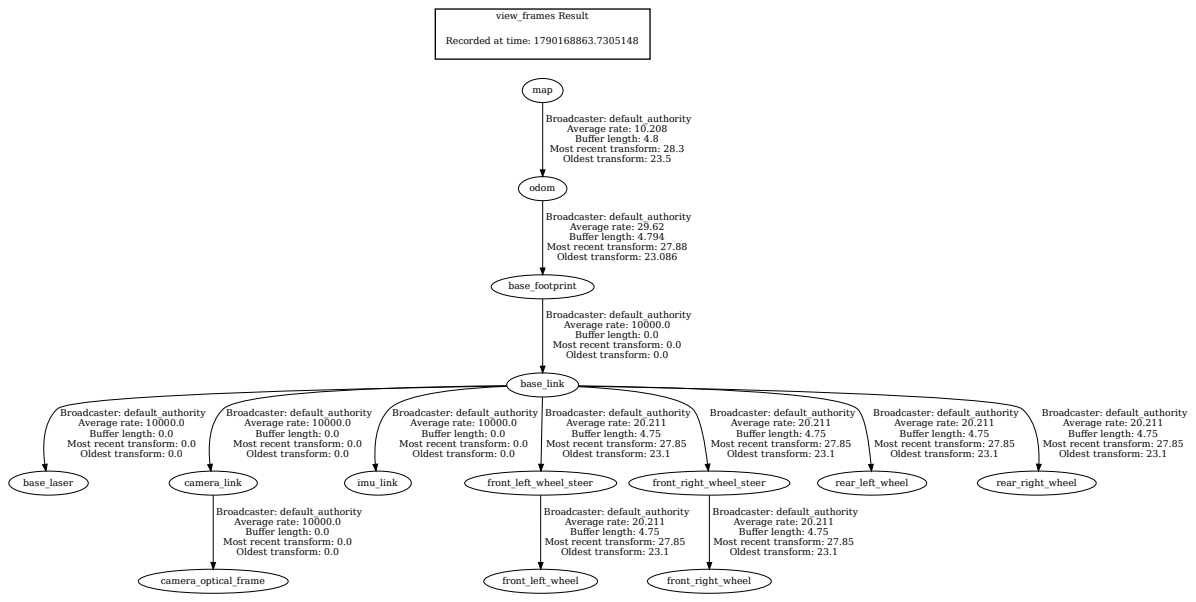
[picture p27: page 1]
view_frames Result; map; odom; base_footprint; base_link; base_laser; camera_link; imu_link; front_left_wheel_steer; front_right_wheel_steer; rear_left_wheel; rear_right_wheel; camera_optical_frame; front_left_wheel; front_right_wheel

Recorded at time: 1790168863.7305148

Broadcaster: default_authority
Average rate: 10.208
Buffer length: 4.8
Most recent transform: 28.3
Oldest transform: 23.5

Average rate: 29.62
Buffer length: 4.794
Most recent transform: 27.88
Oldest transform: 23.086

Average rate: 10000.0
Buffer length: 0.0
Most recent transform: 0.0
Oldest transform: 0.0

Average rate: 20.211
Buffer length: 4.75
Most recent transform: 27.85
Oldest transform: 23.1

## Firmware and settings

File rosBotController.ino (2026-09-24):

#include <Servo.h>



#include <PololuMaestro.h>

#include <micro_ros_arduino.h>
#include <stdio.h>
#include <rcl/rcl.h>
#include <rcl/error_handling.h>
#include <rclc/rclc.h>
#include <rclc/executor.h>
#include <std_msgs/msg/int32.h>
#include <geometry_msgs/msg/twist.h>
#include <std_msgs/msg/string.h>
#include <rosidl_runtime_c/string_functions.h>
#include <rmw_microros/rmw_microros.h>
const int SERVO_PIN = 9;
const int MOTOR_PIN = 12;
char debug_buffer[64];
Servo myServo;
Servo ESC;

rcl_subscription_t servo_subscriber;
std_msgs__msg__Int32 servo_msg;

rcl_publisher_t debug_publisher;
std_msgs__msg__String debug_msg;

rcl_subscription_t motor_subscriber;
std_msgs__msg__Int32 motor_msg;

rcl_subscription_t direction_subscriber;
geometry_msgs__msg__Twist direction_msg; 

rcl_publisher_t button_publisher;
std_msgs__msg__Bool button_msg;

rclc_executor_t executor;
rclc_support_t support;
rcl_allocator_t allocator;
rcl_node_t node;

// Direct variable to hold incoming speed targets from ROS
int target_speed = 1500;
int servo_angle = 80;

#define RCCHECK(fn) { rcl_ret_t temp_rc = fn; if((temp_rc != RCL_RET_OK)){error_loop();}}
#define RCSOFTCHECK(fn) { rcl_ret_t temp_rc = fn; if((temp_rc != RCL_RET_OK)){}}

void error_loop(){
  while(1){
    delay(100);
  }
}

void servo_callback(const void *msvin)
{
  const std_msgs__msg__Int32 *msg = (const std_msgs__msg__Int32 *)msvin;

  int command = msg->data;
  servo_angle = command;

  snprintf(debug_buffer, sizeof(debug_buffer),
         "Speed: %d  Angle: %d",
         target_speed,
         servo_angle);

  rosidl_runtime_c__String__assign(&debug_msg.data, debug_buffer);
  RCSOFTCHECK(rcl_publish(&debug_publisher, &debug_msg, NULL));
}


void motor_callback(const void *msgin)
{
  const std_msgs__msg__Int32 *msg = (const std_msgs__msg__Int32 *)msgin;

  int command = msg->data;

  target_speed = command;

  snprintf(debug_buffer, sizeof(debug_buffer),
         "Speed: %d  Angle: %d",
         target_speed,
         servo_angle);

  rosidl_runtime_c__String__assign(&debug_msg.data, debug_buffer);
  RCSOFTCHECK(rcl_publish(&debug_publisher, &debug_msg, NULL));
}

void keyboard_callback(const void * msgin) {

  const geometry_msgs__msg__Twist *msg_in = (const geometry_msgs__msg__Twist *)msgin;
  float direction = msg_in->linear.x;
  float turn = msg_in->angular.z;
  if (direction == 0.0 && turn == 0.0) {

      target_speed = 1500;
      servo_angle = 80;
  }

  snprintf(debug_buffer, sizeof(debug_buffer),
         "Speed: %d  Angle: %d",
         target_speed,
         servo_angle);

  rosidl_runtime_c__String__assign(&debug_msg.data, debug_buffer);
  RCSOFTCHECK(rcl_publish(&debug_publisher, &debug_msg, NULL));


}

bool wait_for_agent()
{
  const int timeout_ms = 1000;
  const int attempts = 1;

  while (rmw_uros_ping_agent(timeout_ms, attempts) != RMW_RET_OK)
  {
    digitalWrite(LED_BUILTIN, !digitalRead(LED_BUILTIN));
    delay(500);
  }

  return true;
}

void setup() {


  pinMode(LED_BUILTIN, OUTPUT);

  set_microros_transports();

  wait_for_agent();

  myServo.attach(SERVO_PIN);
  myServo.write(80); 
  

  ESC.attach(MOTOR_PIN, 1000, 2000);
  ESC.writeMicroseconds(1500);


  allocator = rcl_get_default_allocator();
  RCCHECK(rclc_support_init(&support, 0, NULL, &allocator));
  RCCHECK(rclc_node_init_default(&node, "teensy", "", &support));
  std_msgs__msg__String__init(&debug_msg);
  RCCHECK(rclc_subscription_init_default(
    &direction_subscriber,
    &node,
    ROSIDL_GET_MSG_TYPE_SUPPORT(geometry_msgs, msg, Twist),
    "cmd_vel"
  ));


  RCCHECK(rclc_subscription_init_default(
    &servo_subscriber,
    &node,
    ROSIDL_GET_MSG_TYPE_SUPPORT(std_msgs, msg, Int32),
    "servo_angle"
  ));

  RCCHECK(rclc_subscription_init_default(
    &motor_subscriber,
    &node,
    ROSIDL_GET_MSG_TYPE_SUPPORT(std_msgs, msg, Int32),
    "motor_speed"
  ));


  RCCHECK(rclc_publisher_init_default(
  &debug_publisher,
  &node,
  ROSIDL_GET_MSG_TYPE_SUPPORT(std_msgs, msg, String),
  "debug_speed"
  ));


  rclc_node_init_default(
      &node,
      "button_node",
      "",
      &support
  );

  rclc_publisher_init_default(
      &button_publisher,
      &node,
      ROSIDL_GET_MSG_TYPE_SUPPORT(std_msgs, msg, Bool),
      "/button"
  );

  RCCHECK(rclc_executor_init(&executor, &support.context, 4, &allocator));
  RCCHECK(rclc_executor_add_subscription(&executor, &servo_subscriber, &servo_msg, &servo_callback, ON_NEW_DATA));
  RCCHECK(rclc_executor_add_subscription(&executor, &motor_subscriber, &motor_msg, &motor_callback, ON_NEW_DATA));
  RCCHECK(rclc_executor_add_subscription(&executor, &direction_subscriber, &direction_msg, &keyboard_callback, ON_NEW_DATA));
  
}

void loop() {
  // Let the micro-ROS executor process incoming messages
  RCSOFTCHECK(rclc_executor_spin_some(&executor, RCL_MS_TO_NS(10)));

  // DIRECT PASSTHROUGH TO THE ESC
  // Updates instantly based on your Python `try/finally` logic safely driving it
  myServo.write(servo_angle);
  ESC.writeMicroseconds(target_speed);
  bool pressed = (digitalRead(BUTTON_PIN) == LOW);

  button_msg.data = pressed;

  rcl_publish(
      &button_publisher,
      &button_msg,
      NULL
  );
}

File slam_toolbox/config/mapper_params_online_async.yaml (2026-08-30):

slam_toolbox:
  ros__parameters:

    # Plugin params
    solver_plugin: solver_plugins::CeresSolver
    ceres_linear_solver: SPARSE_NORMAL_CHOLESKY
    ceres_preconditioner: SCHUR_JACOBI
    ceres_trust_strategy: LEVENBERG_MARQUARDT
    ceres_dogleg_type: TRADITIONAL_DOGLEG
    ceres_loss_function: None

    # ROS Parameters
    odom_frame: odom
    map_frame: map
    base_frame: base_link
    scan_topic: /scan
    use_map_saver: true
    mode: mapping #localization

    # if you'd like to immediately start continuing a map at a given pose
    # or at the dock, but they are mutually exclusive, if pose is given
    # will use pose
    #map_file_name: test_steve
    # map_start_pose: [0.0, 0.0, 0.0]
    #map_start_at_dock: true

    debug_logging: false
    throttle_scans: 1
    transform_publish_period: 0.02 #if 0 never publishes odometry
    map_update_interval: 1.0
    resolution: 0.05
    restamp_tf: false
    min_laser_range: 0.0 #for rastering images
    max_laser_range: 12.0 #for rastering images
    minimum_time_interval: 0.5
    transform_timeout: 0.2
    tf_buffer_duration: 30.0
    stack_size_to_use: 40000000 #// program needs a larger stack size to serialize large maps
    enable_interactive_mode: true

    # General Parameters
    use_scan_matching: true
    use_scan_barycenter: true
    minimum_travel_distance: 0.5
    minimum_travel_heading: 0.5
    check_min_dist_and_heading_precisely: false
    scan_buffer_size: 10
    scan_buffer_maximum_scan_distance: 10.0
    link_match_minimum_response_fine: 0.1  
    link_scan_maximum_distance: 1.5
    loop_search_maximum_distance: 3.0
    do_loop_closing: true 
    loop_match_minimum_chain_size: 10           
    loop_match_maximum_variance_coarse: 3.0  
    loop_match_minimum_response_coarse: 0.35    
    loop_match_minimum_response_fine: 0.45

    # Correlation Parameters - Correlation Parameters
    correlation_search_space_dimension: 0.5
    correlation_search_space_resolution: 0.01
    correlation_search_space_smear_deviation: 0.1 

    # Correlation Parameters - Loop Closure Parameters
    loop_search_space_dimension: 8.0
    loop_search_space_resolution: 0.05
    loop_search_space_smear_deviation: 0.03

    # Scan Matcher Parameters
    distance_variance_penalty: 0.5      
    angle_variance_penalty: 1.0    

    fine_search_angle_offset: 0.00349     
    coarse_search_angle_offset: 0.349   
    coarse_angle_resolution: 0.0349        
    minimum_angle_penalty: 0.9
    minimum_distance_penalty: 0.5
    use_response_expansion: true
    min_pass_through: 2
    occupancy_threshold: 0.1

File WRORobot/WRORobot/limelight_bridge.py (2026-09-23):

#!/usr/bin/env python3

"""
ROS 2 bridge node for Limelight 3A.

Limelight pipelines:

    Pipeline 0:
        Neural Detector
        Detects:
            Red_Obstacle
            Green_Obstacle

    Pipeline 1:
        SnapScript
        Detects:
            Orange_Line

    Pipeline 2:
        SnapScript
        Detects:
            Blue_Line

The SnapScripts send PythonOut:

    [
        detected,
        turnAngle,
        targetX,
        targetY,
        width,
        height,
        pixelError,
        0
    ]

ROS output:

    /limelight/detections

Message type:

    vision_msgs/Detection2DArray

Camera resolution:

    1280 x 960

Camera optical frame:

    X = right
    Y = down
    Z = forward
"""

import threading
from typing import Optional

import rclpy
from rclpy.duration import Duration
from rclpy.node import Node

from builtin_interfaces.msg import Time as TimeMsg
from geometry_msgs.msg import Pose
from vision_msgs.msg import (
    BoundingBox2D,
    Detection2D,
    Detection2DArray,
    ObjectHypothesis,
    ObjectHypothesisWithPose,
    Pose2D,
    Point2D,
)

from WRORobot import limelight
from WRORobot import limelightresults


class LimelightBridge(Node):

    def __init__(self) -> None:
        super().__init__('limelight_bridge')

        # ================================================================
        # CAMERA SETTINGS
        # ================================================================

        self.declare_parameter('image_width', 1280)
        self.declare_parameter('image_height', 960)

        # Nominal intrinsics scaled from 640x480.
        #
        # Replace these with calibrated values if you have them.
        self.declare_parameter('fx', 1054.10)
        self.declare_parameter('fy', 1056.26)
        self.declare_parameter('cx', 640.0)
        self.declare_parameter('cy', 480.0)

        # Physical height of the red/green obstacles.
        self.declare_parameter('pillar_height_m', 0.10)

        # ================================================================
        # LIMELIGHT CONNECTION
        # ================================================================

        self.declare_parameter('fallback_ip', '')
        self.declare_parameter('discovery_timeout_s', 2.0)
        self.declare_parameter('reconnect_period_s', 2.0)

        # ================================================================
        # ROS SETTINGS
        # ================================================================

        self.declare_parameter('publish_rate_hz', 30.0)

        self.declare_parameter(
            'frame_id',
            'camera_optical_frame'
        )

        self.declare_parameter(
            'min_confidence',
            0.0
        )

        # ================================================================
        # PIPELINE SETTINGS
        # ================================================================

        # Your Limelight configuration:
        #
        #   0 = Neural Detector
        #   1 = Orange Line SnapScript
        #   2 = Blue Line SnapScript
        #
        self.neural_pipeline = 0
        self.orange_pipeline = 1
        self.blue_pipeline = 2

        # How long each pipeline remains active.
        #
        # The sequence becomes:
        #
        #   pipeline 0 for 0.30 sec
        #   pipeline 1 for 0.30 sec
        #   pipeline 2 for 0.30 sec
        #   pipeline 0 for 0.30 sec
        #
        self.pipeline_switch_period_s = 0.30

        self._current_pipeline = self.neural_pipeline

        self._last_pipeline_switch_time = (
            self.get_clock().now()
        )

        # ================================================================
        # READ PARAMETERS
        # ================================================================

        self._image_width = int(
            self.get_parameter('image_width').value
        )

        self._image_height = int(
            self.get_parameter('image_height').value
        )

        self._fx = float(
            self.get_parameter('fx').value
        )

        self._fy = float(
            self.get_parameter('fy').value
        )

        self._cx = float(
            self.get_parameter('cx').value
        )

        self._cy = float(
            self.get_parameter('cy').value
        )

        self._pillar_height_m = float(
            self.get_parameter('pillar_height_m').value
        )

        self._fallback_ip = str(
            self.get_parameter('fallback_ip').value
        )

        self._discovery_timeout_s = float(
            self.get_parameter('discovery_timeout_s').value
        )

        self._reconnect_period_s = float(
            self.get_parameter('reconnect_period_s').value
        )

        publish_rate_hz = float(
            self.get_parameter('publish_rate_hz').value
        )

        self._publish_period_s = (
            1.0 / publish_rate_hz
        )

        self._frame_id = str(
            self.get_parameter('frame_id').value
        )

        self._min_confidence = float(
            self.get_parameter('min_confidence').value
        )

        # ================================================================
        # ROS PUBLISHER
        # ================================================================

        self._pub = self.create_publisher(
            Detection2DArray,
            '/limelight/detections',
            10
        )

        # ================================================================
        # LIMELIGHT STATE
        # ================================================================

        self._ll: Optional[
            limelight.Limelight
        ] = None

        self._ll_lock = threading.Lock()

        # ================================================================
        # CONNECT
        # ================================================================

        self._connect_and_start()

        # ================================================================
        # MAIN TIMER
        # ================================================================

        self._timer = self.create_timer(
            self._publish_period_s,
            self._on_timer
        )

        # ================================================================
        # RECONNECT TIMER
        # ================================================================

        self._reconnect_timer = self.create_timer(
            self._reconnect_period_s,
            self._reconnect_if_needed
        )
    # ====================================================================
    # CONNECTION
    # ====================================================================

    def _connect_and_start(self) -> None:

        with self._ll_lock:

            if self._ll is not None:
                return

            address = self._discover_or_fallback()

            if not address:
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

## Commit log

no date Fixed publisher interference
    [wro_bot.urdf.xacro]
2026-06-14 CAD Added
    [Part Studio 2 Copy 1 - Part 1 (1).stl]
2026-06-14 Rename Part Studio 2 Copy 1 - Part 1 (1).stl to WRO Chassis
2026-06-14 Added old version of chassis
    [Part Studio 2 (2).stl]
2026-06-14 Rename Part Studio 2 (2).stl to WRO Old Chassis
2026-06-15 Add files via upload
    Added the code for camera and servo along with the main RobotController
2026-06-18 Add files via upload
    Added teensy node
2026-06-29 Add files via upload
    Code for moving motor or the motor class with ros2
2026-06-29 Update Servo.py
    modified the servo class so it works with ros2
2026-06-29 Add files via upload
    ros robot controller for teensy
2026-07-10 Updated rosBotController.ino so it works for current motor controller
2026-07-10 Updated Motor.py for current motor controller
2026-07-10 Add files via upload
    Added the calibration code for the ESC motor controller
2026-07-15 Update Motor.py
    Simplified topics
2026-07-17 Update motorCalibration.ino
    Making sure everything is updated
2026-07-17 Update Servo.py
    Changed program to receive data from topic command velocity and publish it to topic servo_angle
2026-07-17 Update camera.py
    Updated so it can get specific colored targets and it's location without multiple channel interference
2026-07-20 Update rosBotController.ino
    Added ros2 topic that publishes all the current data coming from teensy.
2026-07-24 Update rosBotController.ino
    Improved keyboard controls so the turning has a dynamic range of motion and the teensy will now wait for micro ros agent to start before running.
2026-07-24 Update Motor.py
    Motor has been updated so that it scales the speed before sending it to teensy.
2026-08-12 Update RobotController.py
    Changed RobotController.py so it incoporates all nodes made so far for servo and motor.
2026-08-16 Update RobotController.py
    Got rid of the attributes for servo and motor class because it was creating unneccessarily instances
2026-08-16 Update Servo.py
    Added main so it's possible to add a node to the launch file and clamped it to the range of 40 to 150 degrees
2026-08-16 Update Motor.py
    Added main so it's possible to add motor node to the launch file
2026-08-23 Added lidar and slam toolbox launch paths to the WRORobot package
2026-08-23 Added the modified config version of slam_toolbox package and added lidar
2026-08-26 added sim world
    [wro_map_nav2_sim.sdf.xacro]
2026-08-26 new map for sim
    [wro_map_nav2_sim.sdf, wro_map_nav2_sim.sdf.xacro]
2026-08-29 saving in case emergency for testing slam
2026-08-31 Major Changes
    [wro_bot.urdf.xacro, wro_field.sdf, wro_field.sdf.xacro]
2026-08-31 Fixed simulation errors
    [wro_bot.urdf.xacro]
2026-09-01 working sim stack + pillar detector; open_challenge WIP
    [wro_bot.urdf.xacro]
2026-09-02 added limelight
    [wro_bot.urdf.xacro]
2026-09-02 Fixed servo code so it scales properly and removed laser scan matcher package and configs
    [Servo.py]
2026-09-05 Lidar open loop fixed and added
2026-09-05 IMU lidar working ish?
2026-09-05 Fix undefined cmd_vel reference in Motor.sendCommand
    The scaling block dereferenced `cmd_vel.linear.x` but the callback parameter is `msg`, so the first cmd_vel message would raise NameError and kill the Motor node. Use `msg.linear.x` and drop the dead assignment above.
    [Motor.py]
2026-09-05 Updated the teensy file to the current version used for driving
2026-09-05 Reversed the servo directions so positive angular.z goes to the left
    [Servo.py]
2026-09-05 Changed Servo so it can accept motor movement while it turns
2026-09-05 Changed Motor and it can accept Servo movement without changing Motor speed
2026-09-05 Removed imu nodes
2026-09-06 Updated otos_node.py to use imu
2026-09-06 Updated otos_node.py so it has imu (got rid of typo)
2026-09-06 Rename WRO Chassis to WROChassis.stl
    [WROChassis.stl]
2026-09-06 Rename WRO Old Chassis to WROOldChassis.stl
    [WROOldChassis.stl]
2026-09-06 Test Obstical Logic
    [wro_field_open.sdf]
2026-09-06 new testy thing
    [wro_field.sdf, wro_field.sdf.xacro, wro_field_open.sdf]
2026-09-06 changed orientation for lidar
    [wro_bot.urdf.xacro]
2026-09-06 changed the yaw (or x axis rotation) to -90 in radians
    [wro_bot.urdf.xacro]
2026-09-06 saftey chatch fix
    [wro_bot.urdf.xacro]
2026-09-07 New Launch and scan filters
2026-09-07 Start adding LIDAR documentation
2026-09-07 Added calibration for otos node
2026-09-08 Added intro for Software and started explaining Teensy 4.1 node
2026-09-08 added the correct otos_node code and calibration
    [calibrate_otos.py, otos_node.py]
2026-09-08 Modles Moved
    [BATRY SWITCH - Part 1.stl, BATTERY HOLDER.stl, BOTTOM PLATE - Part 1.stl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]
2026-09-08 Created Instructions for visualizing laser scan
2026-09-12 Added the calibration settings for limelight
2026-09-13 Rename latest.json to Camera_Config.json so it's more specific
2026-09-13 Saved the training dataset in case of emergency
2026-09-20 new loop nav
    [wro_bot.urdf.xacro]
2026-09-20 nav 2 path
    [wro_bot.urdf.xacro]
2026-09-20 May have fixed the launch file for running open mission
    [limelight_bridge.py]
2026-09-20 fixed the start
    [wro_field.sdf, wro_field.sdf.xacro]
2026-09-21 new waypoint
    [wro_bot.urdf.xacro]
2026-09-23 open challenge sort of works
    [wro_bot.urdf.xacro]
2026-09-23 Changed teensy code back to original
2026-09-24 Corner Logic Changed
    [wro_field_open.sdf]
